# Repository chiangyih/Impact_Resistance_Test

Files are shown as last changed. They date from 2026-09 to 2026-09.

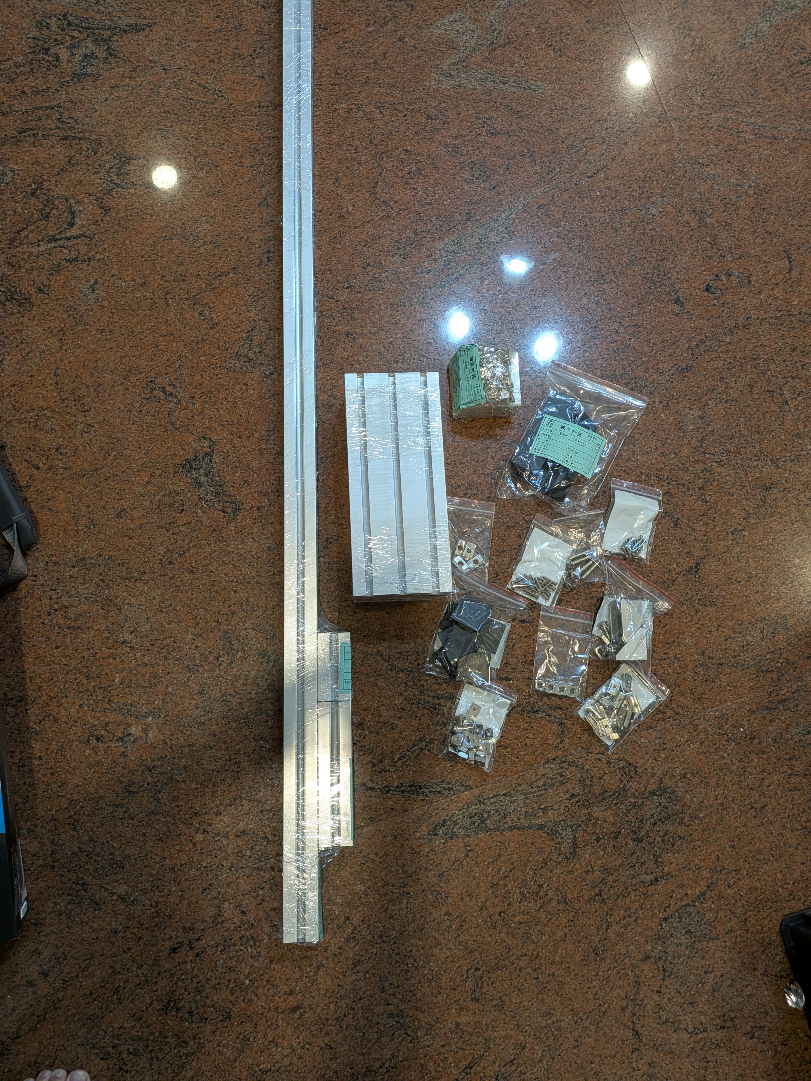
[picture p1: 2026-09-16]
圖片/PXL_20260615_125800659.MP.jpg

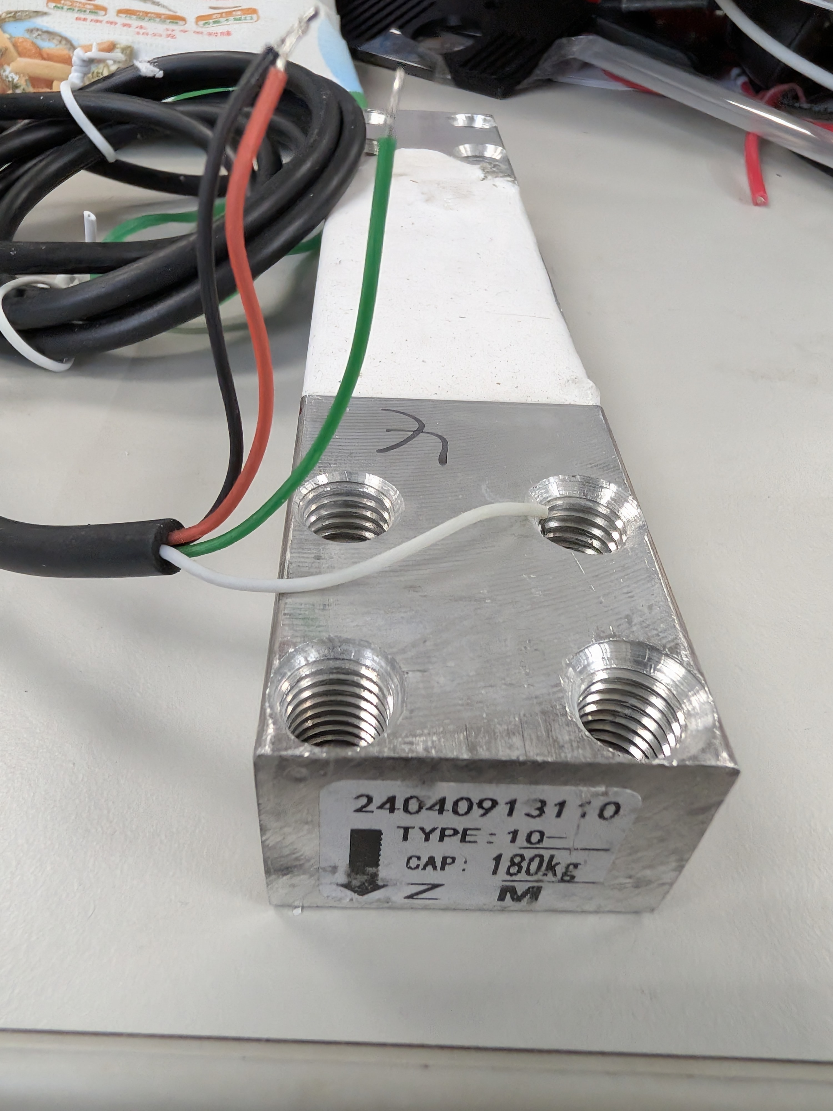
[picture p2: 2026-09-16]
圖片/PXL_20260612_010520091.jpg

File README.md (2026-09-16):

# Impact_Resistance_Test

STF、三浦摺疊與 EVA 落體衝擊緩衝材料試驗平台。

本專案以 NodeMCU-32S（ESP32-WROOM-32）作為控制與資料擷取核心，使用 Adafruit ADXL375 量測掉落平台加速度，使用 Adafruit HX711 搭配荷重元量測底部相對受力，並以兩組 OS25B10 四腳槽型光電開關量測撞擊前近似速度。

## 專案目的

建立可重複的垂直落下衝擊量測系統，比較不同緩衝結構對下列指標的影響：

- 掉落物撞擊前近似速度
- ADXL375 峰值加速度與撞擊作用時間
- Load Cell 傳遞至底座的相對受力
- 緩衝材料的壓縮與永久變形

預計比較的組別包括無緩衝、EVA、PP 三浦摺疊、STF，以及 STF＋三浦摺疊＋EVA 複合結構。

## 實際元件與目前狀態

| 元件 | 目前狀態與用途 |
|---|---|
| NodeMCU-32S／ESP32-WROOM-32 | 主控制器、時間戳與 USB Serial 資料傳輸 |
| Adafruit ADXL375 | ±200 g 三軸加速度計，使用 I²C；照片中的紫色開發板與此型號相符 |
| Adafruit HX711 24-bit ADC | 讀取荷重元；使用 A 通道，RATE 開關規劃使用 80 SPS |
| 四線式 Load Cell | 照片銘牌可讀到 `CAP: 180 kg`；正式校正前仍須以銘牌／資料表確認額定容量與線色 |
| OS25B10 × 2 | 四腳槽型光電開關／光遮斷器，內含紅外線 LED 與光電晶體管；需外接 LED 限流電阻與 Collector 上拉電阻 |
| Relay＋12 V 電磁鐵 | 釋放掉落平台；Relay 型號與觸發邏輯尚待依實物標示確認 |
| 釋放按鈕 | GPIO27，使用內建上拉，按下為 LOW |
| microSD | 尚未由目前照片確認，列為後續選配資料儲存裝置 |

## NodeMCU-32S 腳位總表

這是目前採用的單一腳位配置。未來程式、接線圖與測試紀錄都應以此表為準。

| NodeMCU-32S | 對應元件端子 | 方向 | 用途／備註 |
|---|---|---|---|
| 3V3 | ADXL375 VIN、HX711 VIN、OS25B10 電路 | 電源輸出 | 感測器邏輯電源；不可接 12 V |
| GND | ADXL375 GND、HX711 GND、OS25B10 Emitter／LED Cathode、按鈕、Relay GND | 電源回路 | 邏輯側共地，建議星狀接地 |
| GPIO21 | ADXL375 SDA | I/O | I²C SDA |
| GPIO22 | ADXL375 SCL | I/O | I²C SCL |
| GPIO16 | ADXL375 INT | 輸入（選配） | Data Ready／FIFO／事件中斷；基本輪詢可不接 |
| GPIO17 | ADXL375 I2 | 輸入（選配） | 第二組中斷；目前可不接 |
| GPIO32 | HX711 DATA | 輸入 | HX711 serial data output |
| GPIO33 | HX711 SCK | 輸出 | HX711 serial clock |
| GPIO34 | OS25B10 光閘 1 Collector 節點 | 輸入 | ESP32 輸入專用，沒有內建上拉 |
| GPIO35 | OS25B10 光閘 2 Collector 節點 | 輸入 | ESP32 輸入專用，沒有內建上拉 |
| GPIO26 | Relay IN | 輸出 | 電磁鐵釋放控制；程式需設定高／低觸發 |
| GPIO27 | 釋放按鈕另一端 | 輸入 | 按鈕另一端接 GND，使用 `INPUT_PULLUP` |
| GPIO18 | microSD SCK（選配） | 輸出 | VSPI clock |
| GPIO19 | microSD MISO（選配） | 輸入 | VSPI MISO |
| GPIO23 | microSD MOSI（選配） | 輸出 | VSPI MOSI |
| GPIO5 | microSD CS（選配） | 輸出 | VSPI CS；GPIO5 是啟動相關腳位，SD 模組 CS 應保持上拉 |

GPIO34、GPIO35 只能作輸入，且沒有軟體內建上拉／下拉；OS25B10 必須各自使用外接 10 kΩ 上拉電阻。ADXL375 與 HX711 都使用 3.3 V 邏輯。NodeMCU-32S 不可把 12 V 電磁鐵電源接到 3V3、5V 或 VIN。

## 電源與接地

- NodeMCU-32S 由 USB 供電；感測器由 NodeMCU-32S 的 3V3 供電。
- ADXL375、HX711、OS25B10、按鈕與 Relay 的邏輯側共用 GND。
- 電磁鐵使用獨立 12 V 電源；不要由 ESP32 腳位或 USB 直接供電。
- Relay 模組的 VCC 需依實物標示接額定電源；目前規劃以 5 V Relay 模組為基準。若為非隔離模組，Relay GND 與 ESP32 GND 共地。
- 12 V 高電流線、Relay 線與 Load Cell／I²C 線分開走線，並以星狀方式回到電源地，降低衝擊雜訊。

## ADXL375（Adafruit，I²C）

照片中的紫色板為 Adafruit ADXL375 高 G 加速度計。板上 I²C 預設位址為 `0x53`；I²C 的 SDA、SCL 已有板載上拉與電平轉換，NodeMCU-32S 使用 3.3 V 即可。

| ADXL375 端子 | NodeMCU-32S | 說明 |
|---|---|---|
| VIN | 3V3 | 供電；依板面標示使用 `VIN`，不是 `3Vo` |
| GND | GND | 共地 |
| SDA | GPIO21 | I²C 資料 |
| SCL | GPIO22 | I²C 時脈 |
| CS | 3V3 | I²C 模式；此板預設已拉高，若保持原板設定可不另接 |
| SDO | GND | 使用 I²C 位址 `0x53`；接 3V3 則為 `0x1D` |
| INT | GPIO16（選配） | Data Ready／FIFO／事件中斷 |
| I2 | GPIO17（選配） | 第二組中斷，目前可不接 |
| 3Vo | 不接 | 板上穩壓器的 3.3 V 輸出，不可當作電源輸入 |

ADXL375 應牢固固定在掉落平台上，盡量靠近重心。程式使用 I²C 輪詢時可不接 INT／I2；若要用 Data Ready 或 FIFO 中斷，再接 GPIO16。正式上電前仍應以 I²C scanner 確認 `0x53`。

## HX711（Adafruit）與 Load Cell

照片中的黑色板為 Adafruit HX711 24-bit ADC，板上端子名稱為 `E-`、`A-`、`A+`、`B+`、`B-`、`E+`，邏輯端子為 `VIN`、`GND`、`DATA`、`SCK`、`RATE`。單一四線式荷重元使用 A 通道，B 通道留空。

### HX711 與 NodeMCU-32S

| HX711 端子 | NodeMCU-32S | 說明 |
|---|---|---|
| VIN | 3V3 | 供電；依實物標示使用 `VIN` |
| GND | GND | 共地 |
| DATA | GPIO32 | 資料輸出 |
| SCK | GPIO33 | 時脈輸入 |
| RATE | 不接 GPIO | 使用板上滑動開關；切到 `H` 為 80 SPS，`L` 為 10 SPS |
| VIO（若板上有引出） | 不接 | 板上數位電源穩壓輸出，不是 NodeMCU 電源輸入 |

### Load Cell 與 HX711 端子

| Load Cell 功能／目前照片線色 | HX711 端子 | 備註 |
|---|---|---|
| 激勵正／紅線（暫定） | E+ | 以實際規格或電阻量測確認 |
| 激勵負／黑線（暫定） | E- | 以實際規格或電阻量測確認 |
| 訊號正／綠線（暫定） | A+ | HX711 A 通道 |
| 訊號負／白線（暫定） | A- | HX711 A 通道 |
| B 通道 | B+、B- | 單一荷重元不接 |

紅／黑／綠／白只可作目前接線起點，正式上電前須依荷重元資料表或電阻量測確認。照片銘牌可讀到 `CAP: 180 kg`，因此校正與機構安全檢查暫以 180 kg 額定容量作為待確認資料，不把它當作已完成規格驗證。

Load Cell 機械上應一端固定、一端受力，上方設置剛性壓板；不可將整支樑完全夾死。HX711 最高 80 SPS，適合組別間相對受力比較，不應宣稱為毫秒級真實瞬時峰值力。

## OS25B10 雙光閘

OS25B10 是四腳槽型光電開關／光遮斷器，不是具有 `VCC/GND/OUT` 的數位模組。專案中的實物參考照片為 [OS25B10-紅外線對射光電開關.png](圖片/OS25B10-紅外線對射光電開關.png)。每顆元件需要一個 LED 限流電阻與一個光電晶體管上拉電阻：

```text
每一顆 OS25B10 各自使用一組電阻；兩組輸出節點不可互相短接：

光閘 1：
3.3 V ── 220 Ω ── IR LED Anode
IR LED Cathode ── GND
3.3 V ── 10 kΩ ──┬── Collector
                 └── 輸出節點 ── GPIO34
Emitter ── GND

光閘 2：
3.3 V ── 220 Ω ── IR LED Anode
IR LED Cathode ── GND
3.3 V ── 10 kΩ ──┬── Collector
                 └── 輸出節點 ── GPIO35
Emitter ── GND
```

- 光閘 1 的 Collector 輸出節點接 GPIO34。
- 光閘 2 的 Collector 輸出節點接 GPIO35。
- GPIO34／GPIO35 沒有內建上拉，10 kΩ 必須外接，而且只能拉到 3.3 V。
- 預期未遮光時光電晶體管導通、輸出 LOW；遮光時輸出 HIGH。實際極性仍須在單獨測試時確認。
- OS25B10 四根腳的實體順序目前尚未完成確認。焊接前先用萬用電表二極體檔找出 IR LED 的正負腳，再確認 Collector／Emitter；不可只依封裝外觀猜測。
- 不可將 LED 直接接到 3.3 V，也不可把任何光閘輸出上拉至 5 V。

程式以 `micros()` 記錄兩個 GPIO 的相同邊緣，計算 `v_gate = d / (t2 - t1)`。這是兩閘間平均速度，應稱為「撞擊前近似速度」，不是精確撞擊瞬間速度。

## Relay、電磁鐵與釋放按鈕

### Relay 與 12 V 電磁鐵

Relay 模組的實際型號與觸發邏輯尚待從實物標示確認；目前預留接法如下：

| Relay 端子 | NodeMCU-32S／電源 | 說明 |
|---|---|---|
| IN | GPIO26 | 程式以 `RELAY_ACTIVE_LOW` 選擇高／低觸發 |
| GND | GND | 非隔離模組需共地 |
| VCC | 5 V／VIN 或模組額定電源 | 以 Relay 實物標示為準，不由 GPIO 供電 |

電磁鐵負載側：

```text
獨立 12 V+ ── Relay COM
Relay NO ── 電磁鐵正極
電磁鐵負極 ── 獨立 12 V−
```

電磁鐵兩端並聯飛輪二極體：陰極（有色環端）接電磁鐵正極，陽極接電磁鐵負極。電磁鐵應固定在上方支架，不裝在移動掉落平台上。

### 釋放按鈕

```text
GPIO27 ── 釋放按鈕 ── GND
```

程式設定 `pinMode(27, INPUT_PULLUP)`，按下時讀值為 LOW，並加入按鍵去彈跳。

## microSD（後續選配）

目前尚未從照片確認 microSD 模組，因此不列入已驗證硬體。若後續加入 3.3 V 邏輯相容的 SPI 模組，預留：

| microSD 端子 | NodeMCU-32S |
|---|---:|
| SCK | GPIO18 |
| MISO | GPIO19 |
| MOSI | GPIO23 |
| CS | GPIO5 |
| VCC | 3V3（依模組規格） |
| GND | GND |

GPIO5 是 ESP32 啟動相關腳位，microSD 的 CS 必須在開機時保持適當的高電位；正式接入前要確認模組沒有把 CS 強制拉低。若模組接受 5 V 供電，仍必須確認其輸出到 ESP32 的邏輯不超過 3.3 V。

## 量測與資料品質限制

- 雙光閘應盡量靠近撞擊面；第二光閘到撞擊面的距離需固定或做修正。
- 雙光閘計算的是兩閘間平均速度，不能直接當作撞擊瞬間速度。
- HX711 的取樣率有限，主要用於不同材料組別的相對比較。
- ADXL375 應固定牢靠，避免感測器本體晃動造成假峰值。
- Load Cell 線與 I²C 線遠離 USB、Relay 與電磁鐵高電流線路。
- 目前尚未完成整體實體接線、感測器讀值、Load Cell 校正或正式落下測試。

## Arduino CLI 編譯與燒錄

本專案使用下列 Arduino CLI 執行檔：

```text
C:\Program Files\Arduino CLI\arduino-cli.exe
```

PowerShell 範例：

```powershell
$cli = 'C:\Program Files\Arduino CLI\arduino-cli.exe'
& $cli board list
& $cli compile --fqbn esp32:esp32:nodemcu-32s <sketch-folder>
& $cli upload --port COMx --fqbn esp32:esp32:nodemcu-32s <sketch-folder>
```

正式編譯前先以 `board list` 確認實際 COM 埠，並確認已安裝 ESP32 Arduino core 與 `nodemcu-32s` FQBN。

### 01-irt.ino 第一版簡易測試程式

程式位置為 `01-irt/01-irt.ino`，用途是先確認 ESP32 能否收到下列元件資料：

- Adafruit ADXL375：I²C 掃描、初始化與 X／Y／Z 加速度（m/s²）。
- Adafruit HX711：A 通道增益 128 的原始 ADC 值；未校正、未換算重量。
- OS25B10 光閘一／二：GPIO34／GPIO35 的 HIGH／LOW 狀態。

本測試程式需要安裝 `Adafruit ADXL375`、`Adafruit HX711` 及其相依函式庫；Arduino CLI 可使用下列指令編譯：

```powershell
$cli = 'C:\Program Files\Arduino CLI\arduino-cli.exe'
& $cli lib install 'Adafruit ADXL375' 'Adafruit HX711'
& $cli compile --fqbn esp32:esp32:nodemcu-32s .\01-irt
& $cli upload --port COMx --fqbn esp32:esp32:nodemcu-32s .\01-irt
& $cli monitor --port COMx --config baudrate=115200
```

燒錄前先以 `board list` 確認 `COMx`；序列埠監控視窗應設定為 115200 baud。若 HX711 未就緒，程式等待 1 秒後輸出逾時並繼續顯示其他感測器；OS25B10 必須依接線規格使用外接 10 kΩ 上拉，不能只靠程式設定內建上拉。

## 目前檔案

- `01-irt/01-irt.ino`：第一版簡易感測器接線測試程式，所有程式碼行均附正體中文註解。
- `handoff.md`：完整專題交接紀錄、設計背景與接線修訂。
- `auto-git-watch.ps1`：檔案變更自動 commit／push 監看器。
- `圖片/`：目前取得的元件與機構照片。
- `零件1.stp`：STEP 機械模型。
- `零件1.stl`：STL 網格模型。

## Git 自動同步

遠端儲存庫：<https://github.com/chiangyih/Impact_Resistance_Test>

目前已設定目前 Windows 使用者登入時啟動自動監看器。監看器每 5 秒檢查變更，等待 3 秒後自動建立 commit 並推送至 `origin/main`；不使用 force push。紀錄位於：

```text
%LOCALAPPDATA%\Impact_Resistance_Test\auto-git-watch.log
```

所有新增或修改的檔案都可能被自動提交，請勿將密碼、Token、私鑰或其他秘密放入此專案資料夾。

## 後續工作

1. 用萬用電表確認兩顆 OS25B10 的 LED／Collector／Emitter 實體腳位。
2. 完成雙光閘輸出波形與必要的比較器／施密特觸發器評估。
3. 以 I²C scanner 與 Adafruit Arduino library 完成 ADXL375 單獨讀值測試。
4. 依 Load Cell 規格確認線色、額定容量，完成 HX711 靜態校正。
5. 確認 Relay 模組額定電壓與 HIGH／LOW trigger，完成電磁鐵空載釋放測試。
6. 完成 ESP32 時間同步、雙光閘中斷與資料記錄程式。
7. 先進行低高度、低重量測試，再進入緩衝材料比較實驗。

## 參考資料

- [Adafruit HX711 24-bit ADC](https://learn.adafruit.com/adafruit-hx711-24-bit-adc)
- [Adafruit HX711 Pinouts](https://learn.adafruit.com/adafruit-hx711-24-bit-adc/pinouts)
- [Adafruit ADXL375 Pinouts](https://learn.adafruit.com/adafruit-adxl375/pinouts)
- [Seeed Studio OS25B10 Photo Interrupter](https://wiki.seeedstudio.com/ja/Photo_interrupter_OS25B10/)
- [Espressif Arduino-ESP32 NodeMCU-32S variant](https://github.com/espressif/arduino-esp32/blob/master/variants/nodemcu-32s/pins_arduino.h)
- [Espressif ESP32-WROOM-32 datasheet](https://documentation.espressif.com/esp32-wroom-32_datasheet_en.html)

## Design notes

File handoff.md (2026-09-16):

# handoff.md

## 專題交接紀錄：STF＋三浦摺疊衝擊緩衝試驗台

### 一、專題核心目標
本專題主要希望建立一套可重複的落下衝擊試驗裝置，用來比較不同緩衝結構對衝擊的吸收與減緩效果。

目前關注的緩衝結構包含：
- STF（Shear Thickening Fluid，剪切增稠流體）
- 三浦摺疊（Miura-ori）結構
- EVA 內襯
- 上述材料的複合組合

研究核心問題：
> STF、三浦摺疊與 EVA 是否能透過延長撞擊作用時間、增加變形行程與耗散能量，降低峰值加速度與傳遞到底部的衝擊力？

---

## 二、目前使用／規劃的主要硬體

### 1. ESP32
用途：
- 作為整套裝置的控制與資料擷取核心
- 控制電磁鐵釋放
- 讀取 ADXL375
- 讀取 HX711
- 讀取雙光閘
- 記錄釋放與通過光閘的時間
- 計算速度、合成加速度等資料
- 可搭配 microSD 儲存 CSV
- 可透過 USB Serial 傳輸資料到電腦

NodeMCU-32S 的目前接線配置如下；完整端子對照與注意事項見本文件末尾「實際元件接線修訂」及 `README.md`：
- ADXL375 `VIN` → 3V3；`SDA` → GPIO21；`SCL` → GPIO22
- ADXL375 `INT` → GPIO16（選配）；`I2` → GPIO17（選配）
- ADXL375 `CS` → 3V3（I²C）；`SDO` → GND（I²C 位址 `0x53`）
- HX711 `VIN` → 3V3；`DATA` → GPIO32；`SCK` → GPIO33
- HX711 `RATE` 不占用 GPIO，使用板上開關；`H` 為 80 SPS、`L` 為 10 SPS
- OS25B10 光閘 1 Collector 節點 → GPIO34；光閘 2 Collector 節點 → GPIO35
- Relay `IN` → GPIO26
- 釋放按鈕 → GPIO27，按鈕另一端接 GND，使用 `INPUT_PULLUP`
- microSD（後續選配）：SCK → GPIO18、MISO → GPIO19、MOSI → GPIO23、CS → GPIO5

所有感測器邏輯使用 3.3 V 並與 ESP32 共地。GPIO34／GPIO35 為輸入專用腳位，沒有內建上拉／下拉，OS25B10 必須外接 10 kΩ 上拉電阻。

### 2. ADXL375
用途：
- 高 g 值三軸加速度感測器
- 量測掉落滑塊撞擊瞬間的加速度

本專案實際使用照片中的 Adafruit ADXL375 ±200 g breakout。使用 I²C 時，`VIN` 接 NodeMCU-32S 的 3V3，`SDA` 接 GPIO21，`SCL` 接 GPIO22；`CS` 維持高電位以啟用 I²C，`SDO` 接 GND 使用預設位址 `0x53`。`3Vo` 是板上穩壓器輸出，不可當作電源輸入。此板 SDA／SCL 已有板載 10 kΩ 上拉，通常不需再並接 4.7 kΩ。

可取得：
- X 軸加速度 ax
- Y 軸加速度 ay
- Z 軸加速度 az
- 合成加速度
- 峰值加速度
- 撞擊作用時間
- 反彈震盪情形

合成加速度：
a_total = sqrt(ax^2 + ay^2 + az^2)

安裝：
- 固定在掉落滑塊上
- 建議靠近滑塊重心
- 必須固定牢靠，避免感測器本體晃動造成假峰值

### 3. Load Cell
用途：
- 安裝於底部衝擊平台
- 量測撞擊後傳遞至底部平台的受力

目前實物：
- 照片中的荷重元銘牌可讀到 `CAP: 180 kg`；額定容量仍須以完整銘牌／資料表確認
- 不再沿用前版「50 kg」的暫定假設
- 正式測試前需完成荷重元線色確認、機械安裝檢查與 HX711 校正

可量測：
- 荷重元受力原始訊號
- 經校正後的力
- 相對峰值衝擊力
- 不同緩衝組別間的受力差異

注意：
- Load Cell 不能整支完全夾死
- 一般應一端固定、一端受力，使樑體能正常微小變形

### 4. HX711
用途：
- HX711 不是感測器，而是 Load Cell 的放大器與 ADC
- 將 Load Cell 微小電壓訊號放大並轉成 ESP32 可讀取的數位值

訊號鏈：
Load Cell → HX711 → ESP32

目前接線起點（線色仍須量測確認）：
- Load Cell 紅線 → HX711 `E+`
- 黑線 → `E-`
- 綠線 → `A+`
- 白線 → `A-`
- 單一荷重元不使用 `B+`／`B-`

HX711 接 ESP32：
- `VIN` → 3.3V
- `GND` → GND
- `DATA` → GPIO32
- `SCK` → GPIO33
- `RATE` 不接 GPIO，使用板上滑動開關；`H` 為 80 SPS、`L` 為 10 SPS
- `VIO`（若有引出）為板上輸出，保持不接

重要限制：
- HX711 取樣率有限
- 適合科展級相對衝擊力比較
- 不適合宣稱為毫秒級真實瞬時峰值力的精密量測

建議報告敘述：
> 本研究使用 Load Cell 搭配 HX711 量測衝擊傳遞至底座之相對受力變化。由於 HX711 取樣率有限，所得峰值主要用於組別間相對比較，而非精密瞬時峰值力。

---

## 三、線性滑軌與雙滑塊

### 1. 線性滑軌
目前規劃：
- MGN12
- 長度 1000 mm
- 垂直安裝

作用：
- 限制掉落平台只能沿垂直方向移動
- 避免旋轉、偏移與斜撞
- 提高撞擊位置與姿態的一致性
- 提升實驗可重複性

原理：
- 滑塊內部使用循環鋼珠
- 以滾動摩擦降低阻力
- 鋼珠沿精密溝槽滾動，使滑塊做低摩擦直線運動

注意：
- 線性滑軌仍有摩擦
- 實際掉落加速度通常小於 g
- 因此不能只靠 v = sqrt(2gh) 推估真實撞擊速度
- 需要雙光閘校正

### 2. 兩個滑塊
目前建議：
- 同一支線性滑軌上使用兩個滑塊
- 兩個滑塊用同一片剛性掉落平台連接
- 一起上下移動
- 建議間距約 8～12 cm

上滑塊：
- 穩定掉落平台上半部
- 抵抗電磁鐵吸附與配重偏心造成的旋轉
- 改善釋放瞬間姿態

下滑塊：
- 穩定撞擊頭位置
- 降低下半部擺動
- 確保撞擊頭垂直撞在測試材料中心

共同作用：
- 增加抗旋轉能力
- 降低偏心造成的卡滯
- 提高下落與撞擊一致性

---

## 四、雙光閘

### 1. 作用
雙光閘不是用來量加速度或衝擊力。

主要用途：
> 量測掉落滑塊在撞擊前的實際速度。

原因：
- 線性滑軌有摩擦
- 實際撞擊速度不一定等於理論自由落下速度

### 2. 原理
在軌道下段設置兩個光電遮斷感測器：

掉落方向
↓
光閘1
↓ 固定距離 d
光閘2
↓
撞擊面

ESP32 記錄：
- 光閘1時間 t1
- 光閘2時間 t2

兩閘間平均速度：
v = d / (t2 - t1)

### 3. 重要修正
已確認：
> 滑塊通過第二個光閘後，只要尚未撞擊，速度仍會繼續增加。

因此雙光閘直接計算的是：
> 光閘1到光閘2之間的平均速度

而不是精確撞擊瞬間速度。

建議：
- 光閘1、2間距約 5 cm
- 光閘2盡量靠近撞擊面
- 光閘2到撞擊面建議約 1～2 cm
- 將此速度稱為「撞擊前近似速度」

更精確方案：
1. 利用遮光片寬度與通過光閘2的遮光時間估算局部速度
2. 估算滑軌有效加速度後修正至撞擊面
3. 若需要更高精度，可增加第三個光閘

---

## 五、電磁鐵釋放裝置

### 1. 作用
> 在實驗開始前吸住掉落滑塊，ESP32 控制 Relay 斷電後，讓滑塊從固定高度穩定釋放。

電磁鐵不負責驅動滑塊，也不應承受撞擊力。

### 2. 安裝方式
電磁鐵應：
- 固定在滑軌最上方固定架或橫樑
- 吸附面朝下
- 滑塊上方裝平整鐵片給電磁鐵吸住

結構：
上方固定架
↓
電磁鐵
↓
鐵片
↓
掉落平台
↓
兩個線性滑塊
↓
撞擊頭

重要對準：
- 電磁鐵中心
- 鐵片中心
- 滑塊整體重心
- 撞擊頭中心
- 測試材料中心

應盡量在同一直線上。

### 3. 固定方式
建議：
- L 型角碼
- 小型固定板
- 使用電磁鐵附帶螺絲
- 不建議只用熱熔膠或雙面膠

鐵片：
- 一般鐵片或低碳鋼
- 約 1～2 mm 厚
- 不建議鋁片
- 不鏽鋼可能吸力不足

若斷電後殘磁造成不易釋放，可貼極薄透明膠帶減少殘磁黏附。

### 4. Relay 控制
目前規劃不用 MOSFET，採 Relay 控制。

電磁鐵：
- 使用獨立 12V 電源
- 不可直接由 ESP32 供電

接線：
12V+ → Relay COM
Relay NO → 電磁鐵+
電磁鐵- → 12V-

ESP32：
GPIO26 → Relay IN
GND → Relay GND
5V / VIN → Relay VCC

電磁鐵兩端須加飛輪二極體：
- 陰極（白線端）→ 電磁鐵正極
- 陽極 → 電磁鐵負極

可用：
- 1N4007
- 1N5819
- SS14
- FR107

---

## 六、電磁鐵控制程式邏輯

建議：
開機
↓
Relay 啟動
↓
電磁鐵通電吸住滑塊
↓
等待按鈕
↓
ESP32 啟動資料記錄
↓
Relay 斷電
↓
電磁鐵釋放
↓
記錄釋放時間 t0

目前程式建議：
- Relay IN → GPIO26
- 釋放按鈕 → GPIO27
- 使用 INPUT_PULLUP
- 按下為 LOW
- 正式實驗時間基準建議用 micros()
- Serial 可設：
  - a → ARM
  - r → RELEASE

注意：
- Relay 可能為 LOW trigger 或 HIGH trigger
- 程式需設定 RELAY_ACTIVE_LOW

---

## 七、衝擊過程與物理原理

### 1. 落下前
重力位能：
E_p = mgh

### 2. 撞擊前
實際撞擊動能估計：
E_k = 1/2 mv^2

### 3. 撞擊瞬間
衝量：
J = ∫Fdt = Δp

簡化：
F_avg ≈ Δp / Δt

因此：
- 停止時間越短 → 力越大
- 停止時間越長 → 平均力越小

### 4. 壓縮距離
E = ∫Fdx

簡化：
F_avg ≈ E / s

因此：
- 停止距離越短 → 平均力越大
- 停止距離越長 → 平均力越小

---

## 八、不同緩衝材料的作用

### STF
- 高速受剪切時增稠
- 增加顆粒摩擦與流動阻力
- 形成 hydrocluster / force chain / jamming
- 以黏滯、摩擦與流變耗散撞擊能量

注意：
- 太薄、太濃、封裝太滿都可能使峰值反而升高
- STF 較適合作為高速阻尼層，而非唯一緩衝層

### 三浦摺疊
- 透過幾何變形、摺線轉動、面板彎曲吸能
- 增加壓縮行程
- 延長停止距離與時間
- 有機會降低峰值衝擊力

### EVA
- 泡棉壓縮吸能
- 分散接觸壓力
- 防止硬接觸
- 降低觸底造成的第二峰值
- 降低反彈與局部壓力集中

核心觀念：
> 好的緩衝不是讓力消失，而是把原本「短時間、高峰值」的衝擊，轉換成「較長時間、較低峰值」的受力過程。

---

## 九、主要量測值

直接量測：
1. 掉落物質量 m
2. 掉落高度 h
3. 光閘1時間 t1
4. 光閘2時間 t2
5. 光閘間距 d
6. X 軸加速度 ax
7. Y 軸加速度 ay
8. Z 軸加速度 az
9. HX711 原始讀值
10. 測試材料厚度
11. 三浦摺疊測試前後高度
12. 電磁鐵釋放時間 t0

---

## 十、主要計算值

1. 理論位能：E_p = mgh
2. 理論速度：v_theory = sqrt(2gh)
3. 雙光閘平均速度：v_gate = d / (t2 - t1)
4. 實際撞擊動能估計：E_k = 1/2 mv^2
5. 合成加速度：a_total = sqrt(ax^2 + ay^2 + az^2)
6. 峰值加速度 a_max
7. 撞擊作用時間 Δt_impact
8. 校正後受力 F
9. 相對峰值衝擊力 F_max
10. 峰值加速度降低率
11. 相對衝擊力降低率
12. 永久變形量 ΔH = H0 - H1
13. 平均值、標準差、變異係數

---

## 十一、核心分析指標

建議主打：
1. 實際撞擊前速度
2. 實際撞擊動能
3. 峰值加速度
4. 撞擊作用時間
5. 相對峰值衝擊力
6. 加速度降低率
7. 衝擊力降低率
8. 永久變形量

---

## 十二、建議測試組別

至少：
- A：無緩衝
- B：EVA
- C：PP 三浦摺疊
- D：STF
- E：STF + PP 三浦摺疊 + EVA

若時間足夠：
- STF + EVA
- 三浦摺疊 + EVA
- STF + 三浦摺疊

每組建議至少 5 次。

---

## 十三、程式需要負責的五大模組

### 1. 電磁鐵控制
- Relay 控制通電 / 斷電
- 記錄釋放時間 t0

### 2. 雙光閘
- 使用 GPIO 中斷
- 記錄 t1、t2
- 計算通過速度

### 3. ADXL375
- 持續高速讀取
- 記錄 ax、ay、az
- 計算合成加速度
- 找峰值加速度
- 估算撞擊作用時間

### 4. Load Cell + HX711
- 讀取原始值
- 依校正係數換算受力
- 記錄相對峰值力

### 5. 時間同步與資料儲存
所有事件共用同一時間軸：

t = 0        電磁鐵釋放
t = ...      光閘1
t = ...      光閘2
t = ...      撞擊開始
t = ...      加速度峰值
t = ...      Load Cell 相對力峰值
t = ...      撞擊結束

建議：
- 使用 micros()
- microSD 儲存 CSV
- 或 USB Serial 傳至電腦

---

## 十四、建議程式狀態機

WAIT
↓
ARMED
↓
RECORDING
↓
RELEASE
↓
FALLING
↓
IMPACT
↓
FINISHED
↓
READY

意義：
- WAIT：等待操作
- ARMED：電磁鐵吸住滑塊
- RECORDING：感測器預先記錄
- RELEASE：電磁鐵斷電
- FALLING：記錄光閘
- IMPACT：高速記錄衝擊資料
- FINISHED：停止本次試驗
- READY：準備下一次

---

## 十五、microSD 建議

建議 CSV 欄位：

trial_id,group,time_us,release_state,gate1,gate2,ax_g,ay_g,az_g,a_total_g,hx711_raw,force_N

每次實驗摘要：
- trial_id
- group
- mass_g
- height_cm
- v_actual
- impact_energy_J
- peak_acceleration_g
- peak_force_N
- impact_duration_ms
- permanent_deformation_mm

---

## 十六、目前最重要的技術注意事項

1. ADXL375 要牢固固定在掉落滑塊。
2. Load Cell 上方應設剛性上壓板。
3. HX711 適合相對力比較，不宜宣稱精密瞬時峰值。
4. 線性滑軌要垂直並固定牢靠。
5. 兩個滑塊建議間距 8～12 cm。
6. 滑塊重心要靠近滑軌中心線。
7. 電磁鐵固定在上方固定架，不裝在移動滑塊上。
8. 電磁鐵、鐵片、滑塊重心、撞擊頭、測試材料中心盡量對齊。
9. 電磁鐵使用獨立 12V 電源。
10. Relay 控制電磁鐵時必須加飛輪二極體。
11. 雙光閘應盡量靠近撞擊面。
12. 雙光閘測得的是兩閘間平均速度，不是精確撞擊瞬間速度。
13. 若需更精確，可用遮光片寬度計算第二光閘附近局部速度。
14. 正式程式應重視時間同步，建議使用 micros()。
15. 若測試材料厚度不同，應保持光閘2到實際撞擊面的距離一致或做修正。

---

## 十七、目前專題整體架構

ESP32
├─ ADXL375 → 加速度
├─ HX711 → Load Cell → 底部相對受力
├─ 光閘1
├─ 光閘2 → 撞擊前速度
├─ Relay → 12V 電磁鐵 → 滑塊釋放
└─ microSD（建議）→ CSV 資料記錄

機械結構：

上方固定架
↓
電磁鐵
↓
鐵片
↓
掉落平台
├─ 配重
├─ ADXL375
├─ 上滑塊
├─ 下滑塊
└─ 撞擊頭
↓
雙光閘
↓
STF / 三浦摺疊 / EVA
↓
上壓板
↓
Load Cell
↓
底座

---

## 十八、後續建議優先工作

1. 確認 MGN12 滑軌與兩滑塊實際機械尺寸
2. 設計掉落平台與撞擊頭
3. 完成電磁鐵固定架
4. 完成鐵片與電磁鐵對準
5. 完成 Relay 控制與空載釋放測試
6. 完成雙光閘安裝
7. 完成 ADXL375 單獨讀值測試
8. 完成 Load Cell + HX711 靜態校正
9. 完成整體 ESP32 同步程式
10. 先進行低高度、低重量落下測試
11. 確認感測器不飽和、資料不遺失
12. 再進入正式 STF / 三浦摺疊材料比較實驗

---

## 十九、一句話總結

> 本專題利用線性滑軌與電磁鐵建立可重複落下機構，透過雙光閘量測撞擊前速度、ADXL375 量測撞擊加速度、Load Cell + HX711 量測底部傳遞受力，進而比較 STF、三浦摺疊與 EVA 等緩衝結構對峰值加速度、衝擊力、撞擊作用時間與結構變形的影響。

---

## 二十、2026-09-14 本次工作進度

### 1. Git 版本控管與自動同步

已完成：

- 專案資料夾已建立 Git 儲存庫，主要分支為 `main`。
- 已設定遠端：`https://github.com/chiangyih/Impact_Resistance_Test.git`。
- 遠端原有的 `README.md` 已保留，並以一般合併方式整合，未使用強制推送。
- 已建立 `auto-git-watch.ps1`，功能如下：
  - 每 5 秒檢查專案檔案變更。
  - 變更穩定 3 秒後執行 `git add --all`。
  - 自動建立帶有時間的 commit。
  - 自動執行 `git push`。
  - 不執行 force push；push 失敗時保留本地 commit 並記錄錯誤。
- Windows 工作排程建立受到目前權限限制，因此改用目前使用者的登入啟動項：
  `Impact_Resistance_Test_AutoGit`。
- 監看紀錄位置：
  `%LOCALAPPDATA%\Impact_Resistance_Test\auto-git-watch.log`
- 已完成端到端驗證：自動產生 commit `c0c4dee` 並成功推送；目前本地 `main` 與 `origin/main` 同步。
- Git 認證沿用 Windows Git Credential Manager，未將密碼、Token 或私鑰寫入專案檔案。

目前專案檔案：

- `README.md`
- `handoff.md`
- `auto-git-watch.ps1`
- `圖片/`（元件與機構照片）
- `零件1.stp`
- `零件1.stl`

### 2. ESP32 感測電路第一版規劃（已依實物修訂）

目前以 NodeMCU-32S、3.3 V 邏輯為基準：

| 功能 | ESP32 腳位 | 接線規劃 |
|---|---:|---|
| ADXL375 SDA | GPIO21 | I²C SDA |
| ADXL375 SCL | GPIO22 | I²C SCL |
| HX711 DATA | GPIO32 | 資料輸出 |
| HX711 SCK | GPIO33 | 時脈輸入 |
| 雙光閘 1 | GPIO34 | 光電晶體管輸出 |
| 雙光閘 2 | GPIO35 | 光電晶體管輸出 |
| ADXL375 INT（選配） | GPIO16 | Data Ready／FIFO／事件中斷 |
| ADXL375 I2（選配） | GPIO17 | 第二組中斷 |
| Relay IN | GPIO26 | 電磁鐵釋放控制 |
| 釋放按鈕 | GPIO27 | 按鈕另一端接 GND，使用 INPUT_PULLUP |
| microSD SCK（選配） | GPIO18 | VSPI |
| microSD MISO（選配） | GPIO19 | VSPI |
| microSD MOSI（選配） | GPIO23 | VSPI |
| microSD CS（選配） | GPIO5 | VSPI；GPIO5 為啟動相關腳位 |

ADXL375：

- 本專案實際使用 Adafruit ADXL375 ±200 g breakout，I²C 預設位址為 `0x53`。
- 開發板 `VIN` → NodeMCU-32S 3.3 V，`GND` 共地；`3Vo` 是板上輸出，保持不接。
- `SDA` → GPIO21，`SCL` → GPIO22。
- `CS` 拉至 3.3 V 以使用 I²C；`SDO` 接 GND 使用 `0x53`，接 3.3 V 則使用 `0x1D`。
- 此 Adafruit breakout 的 SDA／SCL 已有板載 10 kΩ 上拉與電平轉換，通常不需再加 4.7 kΩ。
- `INT` 可接 GPIO16，`I2` 可接 GPIO17；只使用 I²C 輪詢時可不接。
- 若後續需要較高資料率，再評估改用 SPI。

HX711 與 Load Cell：

- 本專案實際使用 Adafruit HX711 breakout；`VIN` 使用 3.3 V，`DATA` 接 GPIO32，`SCK` 接 GPIO33，GND 共地。
- `RATE` 不占用 ESP32 GPIO，使用板上滑動開關；`H` 為 80 SPS、`L` 為 10 SPS。
- `VIO`（若有引出）是板上數位電源輸出，保持不接。
- Load Cell 的激勵線接 `E+`／`E-`，訊號線接 `A+`／`A-`。
- 照片中的四線荷重元銘牌可讀到 `CAP: 180 kg`；紅／黑／綠／白線色僅作接線起點，實際仍須依荷重元資料表或電阻量測確認。
- 單一荷重元不使用 `B+`／`B-`。
- HX711 適合相對受力與低速荷重比較，不將其結果宣稱為毫秒級真實瞬時峰值力。

### 3. OS25B10 雙光閘修正

已確認目前選用的 `OS25B10` 是四腳槽型光電開關／光遮斷器，不是具備 `VCC/GND/OUT` 的數位模組；實物參考照片為 `圖片/OS25B10-紅外線對射光電開關.png`。每個光閘建議使用：

```text
光閘 1（獨立一組電阻）：
3.3 V ── 220 Ω ── IR LED Anode
IR LED Cathode ── GND
3.3 V ── 10 kΩ ──┬── Collector
                 └── 輸出節點 ── GPIO34
Emitter ── GND

光閘 2（獨立一組電阻）：
3.3 V ── 220 Ω ── IR LED Anode
IR LED Cathode ── GND
3.3 V ── 10 kΩ ──┬── Collector
                 └── 輸出節點 ── GPIO35
Emitter ── GND
```

- 光閘 1 輸出接 GPIO34，光閘 2 輸出接 GPIO35。
- GPIO34／GPIO35 為輸入專用腳位，沒有內建上拉電阻，因此必須使用外接 10 kΩ。
- 未遮光時光電晶體管導通，輸出通常為 LOW；遮光時輸出被拉高為 HIGH。
- 四根腳位的實際順序尚未完成確認；正式焊接前須用二極體檔找出 LED 腳位，再確認 Collector／Emitter。
- 不可將 OS25B10 的任何輸出上拉至 5 V，也不可把 LED 直接接到 3.3 V。

### 4. 已驗證與待完成事項

已驗證：

1. Git 儲存庫、遠端 `origin` 與 `main` 分支正常。
2. 自動檔案監看、commit 與 push 已實際成功執行。
3. 目前尚未對 ESP32、ADXL375、HX711、Load Cell 或 OS25B10 進行完整實體接線與量測；元件型號與照片辨識已完成初步確認。

待完成：

1. 確認 OS25B10 實際腳位順序與遮光輸出波形。
2. 完成雙光閘原理圖與必要的比較器／施密特觸發器評估。
3. 以 I²C scanner 確認 ADXL375 位址並完成單獨讀值測試。
4. 依荷重元規格確認線色與額定容量，完成 Load Cell＋HX711 靜態校正。
5. 確認 Relay 模組額定電壓與 HIGH／LOW trigger，完成電磁鐵空載釋放測試。
6. 完成 ESP32 時間同步、雙光閘中斷與資料記錄程式。
7. 使用 Arduino CLI 進行 NodeMCU-32S 編譯與燒錄測試。
8. 先進行低高度、低重量測試，再進行正式緩衝材料比較。

---

## 二十一、2026-09-16 實際元件接線對應修訂

本節為目前最具體的接線版本，並覆蓋前文僅以「建議」描述的腳位。`README.md` 也已同步更新。

### 1. 已由照片確認的元件

- NodeMCU-32S／ESP32-WROOM-32：主控制器。
- Adafruit ADXL375 紫色 breakout：±200 g 三軸加速度計，使用 I²C。
- Adafruit HX711 黑色 breakout：24-bit ADC，使用 A 通道讀取荷重元。
- 四線式 Load Cell：照片銘牌可讀到 `CAP: 180 kg`；完整額定規格與線色仍須再確認。
- 圖片資料夾內另可見線性滑軌、鋁合金基座與安裝零件。

OS25B10 的實物照片已補充為 `圖片/OS25B10-紅外線對射光電開關.png`，可確認其為四腳槽型光電開關／光遮斷器，內含紅外線 LED 與光電晶體管；但四腳實體順序仍需依實物量測確認。Relay、釋放按鈕與 microSD 的功能已納入系統規劃，其中 Relay 型號／觸發邏輯及 microSD 模組目前仍需依實物確認。

### 2. NodeMCU-32S 腳位總表

| NodeMCU-32S | 實際／規劃元件端子 | 方向 | 說明 |
|---|---|---|---|
| 3V3 | ADXL375 VIN、HX711 VIN、OS25B10 電路 | 電源 | 感測器使用 3.3 V；不可接 12 V |
| GND | ADXL375 GND、HX711 GND、OS25B10、按鈕、Relay 邏輯側 | 電源 | 邏輯側共地，建議星狀接地 |
| GPIO21 | ADXL375 SDA | I/O | I²C SDA |
| GPIO22 | ADXL375 SCL | I/O | I²C SCL |
| GPIO16 | ADXL375 INT（選配） | 輸入 | Data Ready／FIFO／事件中斷 |
| GPIO17 | ADXL375 I2（選配） | 輸入 | 第二組中斷 |
| GPIO32 | HX711 DATA | 輸入 | HX711 資料輸出 |
| GPIO33 | HX711 SCK | 輸出 | HX711 時脈 |
| GPIO34 | OS25B10 光閘 1 Collector 節點 | 輸入 | 輸入專用，沒有內建上拉 |
| GPIO35 | OS25B10 光閘 2 Collector 節點 | 輸入 | 輸入專用，沒有內建上拉 |
| GPIO26 | Relay IN | 輸出 | 電磁鐵釋放；需設定高／低觸發 |
| GPIO27 | 釋放按鈕 | 輸入 | 按鈕另一端接 GND，使用 `INPUT_PULLUP` |
| GPIO18 | microSD SCK（選配） | 輸出 | VSPI clock |
| GPIO19 | microSD MISO（選配） | 輸入 | VSPI MISO |
| GPIO23 | microSD MOSI（選配） | 輸出 | VSPI MOSI |
| GPIO5 | microSD CS（選配） | 輸出 | VSPI CS；開機時需保持適當高電位 |

### 3. Adafruit ADXL375 實際接法

| ADXL375 端子 | NodeMCU-32S | 備註 |
|---|---|---|
| `VIN` | 3V3 | 供電；`3Vo` 是板上輸出，不可拿來供電 |
| `GND` | GND | 共地 |
| `SDA` | GPIO21 | I²C 資料 |
| `SCL` | GPIO22 | I²C 時脈 |
| `CS` | 3V3 | I²C 模式；板上預設已拉高，可保持原設定 |
| `SDO` | GND | I²C 位址 `0x53`；接 3V3 則為 `0x1D` |
| `INT` | GPIO16（選配） | 可不接，輪詢模式不需要 |
| `I2` | GPIO17（選配） | 第二組中斷，可不接 |
| `3Vo` | 不接 | 穩壓器 3.3 V 輸出 |

Adafruit breakout 的 SDA／SCL 已有板載 10 kΩ 上拉與電平轉換，通常不需再並接外部 4.7 kΩ。正式上電後先以 I²C scanner 確認 `0x53`。

### 4. Adafruit HX711 與荷重元實際接法

HX711：

- `VIN` → NodeMCU-32S `3V3`
- `GND` → `GND`
- `DATA` → GPIO32
- `SCK` → GPIO33
- `RATE` 不接 GPIO，使用板上滑動開關；`H` 為 80 SPS，`L` 為 10 SPS
- `VIO`（若有引出）為板上輸出，保持不接

單一四線式荷重元使用 A 通道：

| 荷重元功能／照片線色（暫定） | HX711 端子 |
|---|---|
| 激勵正／紅線 | `E+` |
| 激勵負／黑線 | `E-` |
| 訊號正／綠線 | `A+` |
| 訊號負／白線 | `A-` |
| 未使用的第二通道 | `B+`、`B-` 保持不接 |

上述紅／黑／綠／白僅為照片與常見配置的接線起點；正式上電前仍要用資料表或電阻量測確認。照片可讀到 `CAP: 180 kg`，在規格確認完成前不得把此容量視為已驗證值。HX711 最高 80 SPS，量測結果僅作相對受力比較。

### 5. OS25B10 雙光閘電路

OS25B10 是四腳槽型光電開關／光遮斷器，每顆各使用一組 220 Ω LED 限流電阻與 10 kΩ 光電晶體管上拉電阻；實物照片為 `圖片/OS25B10-紅外線對射光電開關.png`：

```text
光閘 1（獨立一組電阻）：
3.3 V ── 220 Ω ── IR LED Anode
IR LED Cathode ── GND
3.3 V ── 10 kΩ ──┬── Collector
                 └── 輸出節點 ── GPIO34
Emitter ── GND

光閘 2（獨立一組電阻）：
3.3 V ── 220 Ω ── IR LED Anode
IR LED Cathode ── GND
3.3 V ── 10 kΩ ──┬── Collector
                 └── 輸出節點 ── GPIO35
Emitter ── GND
```

上圖的兩個 Collector 節點是分開的兩組電路，不是互相短接。GPIO34／GPIO35 沒有內建上拉，且輸出節點只能拉到 3.3 V。預期未遮光為 LOW、遮光為 HIGH，但實際極性需單獨量測確認。四腳實體順序尚未確認，焊接前先用萬用電表二極體檔找出 LED 腳位，再確認 Collector／Emitter。

### 6. Relay、電磁鐵與按鈕

Relay 邏輯側目前預留：

- `IN` → GPIO26
- `GND` → ESP32 GND（非隔離模組）
- `VCC` → Relay 實物標示的額定電源；目前以 5 V 模組為基準

電磁鐵負載側使用獨立 12 V：

```text
12 V+ ── Relay COM
Relay NO ── 電磁鐵正極
電磁鐵負極 ── 12 V−
```

電磁鐵兩端並聯飛輪二極體，陰極（有色環端）接正極，陽極接負極。Relay 型號與 HIGH／LOW trigger 尚未確認，程式需保留 `RELAY_ACTIVE_LOW` 設定。

釋放按鈕接法：

```text
GPIO27 ── 按鈕 ── GND
```

程式使用 `INPUT_PULLUP`，按下為 LOW，並加入去彈跳。

### 7. microSD 選配接法

目前未由照片確認 microSD 模組。若後續使用 3.3 V 邏輯相容的 SPI 模組，接 `SCK/GPIO18`、`MISO/GPIO19`、`MOSI/GPIO23`、`CS/GPIO5`、`VCC/3V3`、`GND/GND`；GPIO5 為啟動相關腳位，需確認 CS 開機時不被強制拉低。

### 8. Arduino CLI 工具

ESP32 程式使用：

```text
C:\Program Files\Arduino CLI\arduino-cli.exe
```

編譯與燒錄前先用 `board list` 確認 COM 埠，並確認 ESP32 Arduino core 與 `esp32:esp32:nodemcu-32s` FQBN 已安裝。所有實體接線與感測器讀值仍須先完成低風險測試，再進行正式落下試驗。

### 9. 官方參考

- Adafruit HX711：<https://learn.adafruit.com/adafruit-hx711-24-bit-adc>
- Adafruit HX711 Pinouts：<https://learn.adafruit.com/adafruit-hx711-24-bit-adc/pinouts>
- Adafruit ADXL375 Pinouts：<https://learn.adafruit.com/adafruit-adxl375/pinouts>
- Seeed Studio OS25B10 Photo Interrupter：<https://wiki.seeedstudio.com/ja/Photo_interrupter_OS25B10/>
- Arduino-ESP32 NodeMCU-32S 腳位定義：<https://github.com/espressif/arduino-esp32/blob/master/variants/nodemcu-32s/pins_arduino.h>

### 10. 2026-09-16 第一版簡易測試程式

已新增 `01-irt/01-irt.ino`，這是目前第一版的簡易測試程式，目的只在確認 ESP32 能收到三類實際元件的資料，不包含正式落下測試、速度計算、校正、資料記錄或 Relay 控制。程式每一個非空程式碼行均附正體中文註解。

測試內容：

1. ADXL375 使用 GPIO21／GPIO22 的 I²C，先掃描匯流排，再以預設位址 `0x53` 初始化，週期性輸出 X／Y／Z 加速度，單位為 `m/s²`。
2. HX711 使用 GPIO32／GPIO33，以 A 通道增益 128 讀取原始 ADC 值；程式不執行重量校正，並對 DATA 未就緒加入 1 秒逾時保護，避免接線錯誤造成永久卡住。
3. OS25B10 光閘一／二分別讀取 GPIO34／GPIO35，輸出實際 HIGH／LOW；依目前電路預期未遮光為 LOW、遮光為 HIGH，但仍須以實物量測確認極性。

本機已用 `C:\Program Files\Arduino CLI\arduino-cli.exe` 搭配 `esp32:esp32:nodemcu-32s` 編譯通過。編譯函式庫為 `Adafruit ADXL375`、`Adafruit HX711` 及其相依函式庫。程式檔案標頭與開機訊息均已註明「尚未實際燒錄驗證」。當次 `board list` 僅辨識到 `COM1 Unknown`，尚未完成 NodeMCU-32S 實機燒錄與感測器讀值驗證。

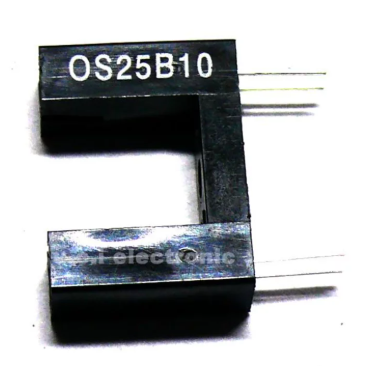
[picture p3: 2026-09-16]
圖片/OS25B10-紅外線對射光電開關.png

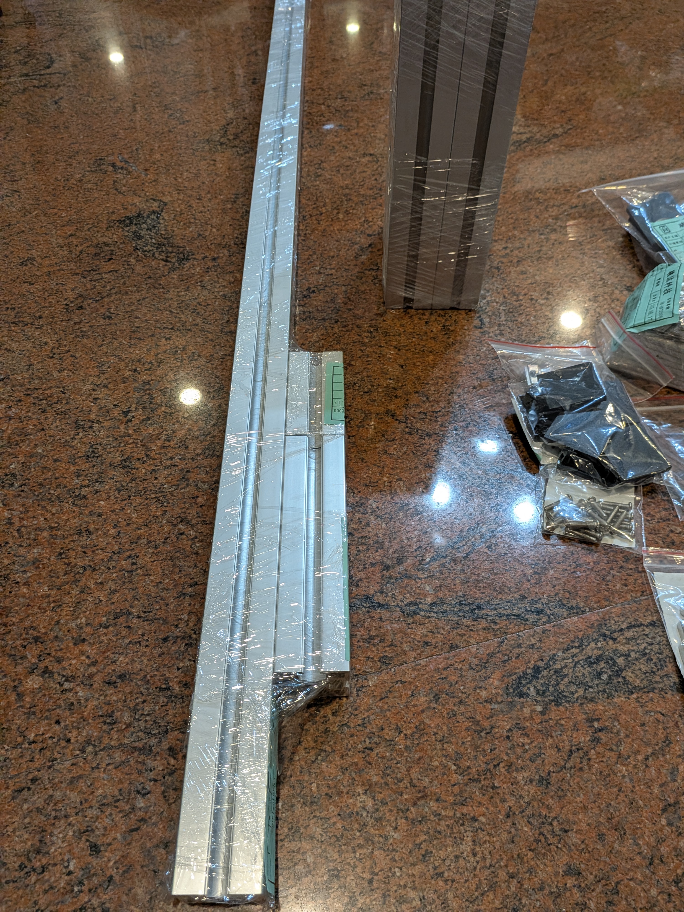
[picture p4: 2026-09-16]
圖片/PXL_20260615_125853231.MP.jpg

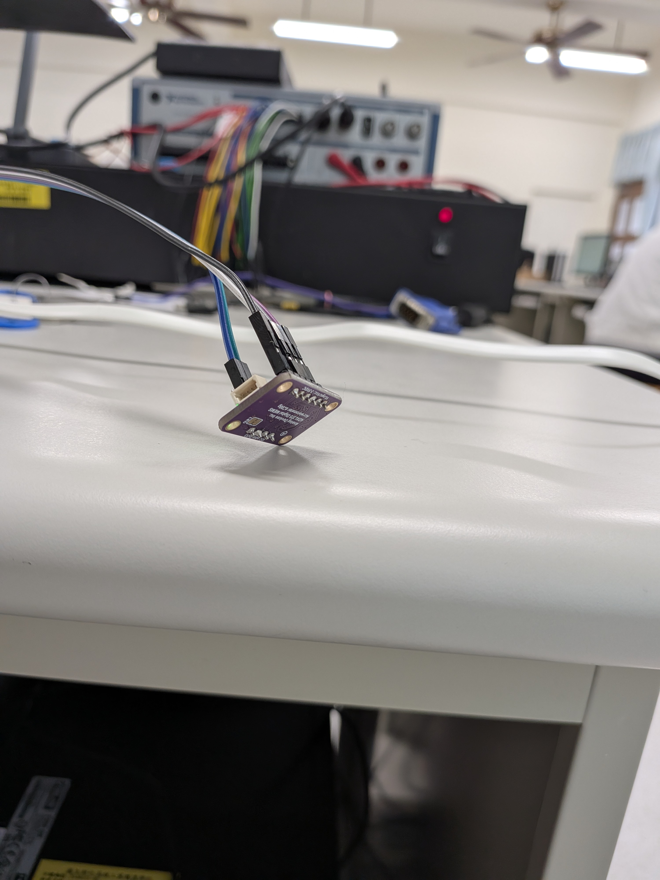
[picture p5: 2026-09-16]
圖片/PXL_20260611_024923133.MP.jpg

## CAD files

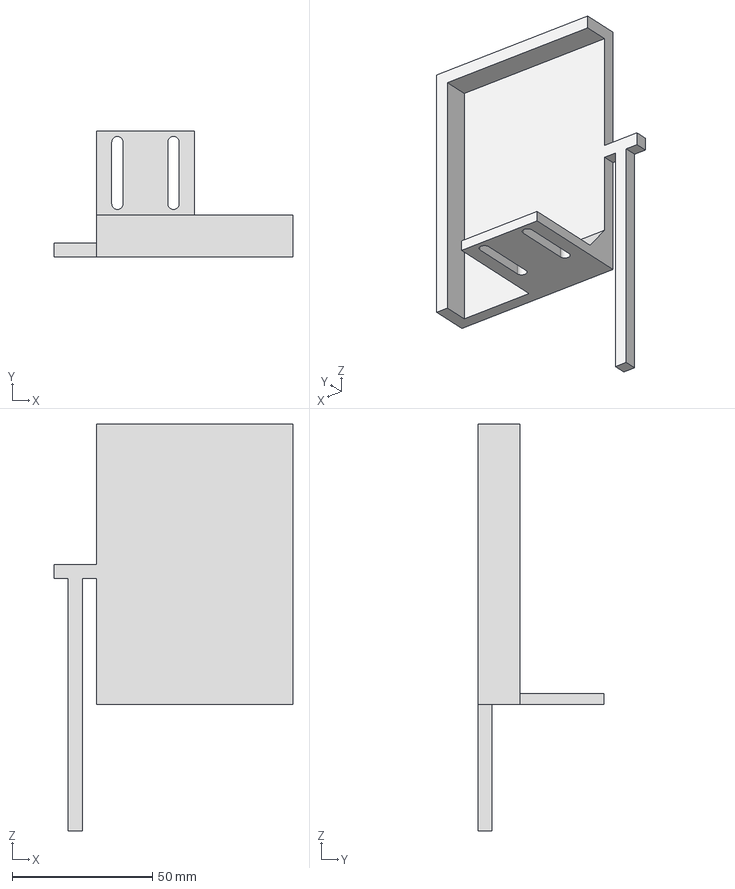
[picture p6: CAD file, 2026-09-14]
零件1.stp
85.0 x 45.0 x 145.0 mm

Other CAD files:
零件1.stl

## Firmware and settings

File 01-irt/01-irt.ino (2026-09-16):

// ============================================================================ // 本檔案為 01-irt.ino 第一版簡易測試程式（簡易測試版）。
// 本程式只驗證 ADXL375、HX711 與兩組 OS25B10 是否能由 ESP32 讀到資料。 // 本行說明測試範圍。
// 本程式不包含正式落下測試、速度計算、校正、資料記錄或 Relay 控制。 // 本行說明目前未包含的功能。
// 本程式目前僅完成編譯檢查，尚未在實體 NodeMCU-32S 上實際燒錄驗證。 // 本行明確標示目前驗證狀態。
// 開啟序列埠監控視窗並設定為 115200 baud，即可查看測試結果。 // 本行說明操作方式。
// ============================================================================ // 本行為檔案標題結束線。

#include <Arduino.h> // 載入 Arduino 基本型別、GPIO、時間與 Serial 功能。
#include <Wire.h> // 載入 I²C 通訊功能，供 ADXL375 使用。
#include <Adafruit_Sensor.h> // 載入 Adafruit Unified Sensor 的事件資料型別。
#include <Adafruit_ADXL375.h> // 載入 Adafruit ADXL375 感測器函式庫。
#include <Adafruit_HX711.h> // 載入 Adafruit HX711 ADC 函式庫。

const uint8_t ADXL375_SDA_PIN = 21; // 設定 ADXL375 SDA 接到 NodeMCU-32S GPIO21。
const uint8_t ADXL375_SCL_PIN = 22; // 設定 ADXL375 SCL 接到 NodeMCU-32S GPIO22。
const uint8_t HX711_DATA_PIN = 32; // 設定 HX711 DATA 接到 NodeMCU-32S GPIO32。
const uint8_t HX711_SCK_PIN = 33; // 設定 HX711 SCK 接到 NodeMCU-32S GPIO33。
const uint8_t OS25B10_GATE1_PIN = 34; // 設定 OS25B10 光閘一 Collector 節點接到 GPIO34。
const uint8_t OS25B10_GATE2_PIN = 35; // 設定 OS25B10 光閘二 Collector 節點接到 GPIO35。
const uint8_t ADXL375_I2C_ADDRESS = 0x53; // 設定 SDO 接地時 ADXL375 的預設 I²C 位址。
const uint32_t SERIAL_BAUD_RATE = 115200; // 設定序列埠傳輸速率為 115200 baud。
const uint32_t REPORT_INTERVAL_MS = 500; // 設定每 500 毫秒輸出一次感測器資料。
const uint32_t HX711_READY_TIMEOUT_MS = 1000; // 設定等待 HX711 DATA 就緒的最長時間。

Adafruit_ADXL375 g_adxl375(12345, &Wire); // 建立使用硬體 I²C 的 ADXL375 物件並指定識別碼。
Adafruit_HX711 g_hx711(HX711_DATA_PIN, HX711_SCK_PIN); // 建立使用 GPIO32 與 GPIO33 的 HX711 物件。
bool g_adxl375_ready = false; // 保存 ADXL375 初始化是否成功的狀態。
bool g_hx711_ready = false; // 保存 HX711 初始化是否完成的狀態。
uint32_t g_last_report_ms = 0; // 保存上一次輸出資料的時間戳。

void printI2CScan(); // 宣告 I²C 掃描函式，先確認 ADXL375 是否出現在匯流排上。
bool readHX711RawWithTimeout(int32_t &raw_value); // 宣告具逾時保護的 HX711 原始值讀取函式。
void printSensorValues(); // 宣告感測器資料輸出函式。

void setup() { // Arduino 開機後只執行一次的初始化函式。
  Serial.begin(SERIAL_BAUD_RATE); // 啟動 USB 序列埠，讓 ESP32 回傳測試結果。
  delay(500); // 等待序列埠與 USB 轉換器穩定。
  Serial.println(); // 在序列埠輸出一個空白行，方便閱讀。
  Serial.println("========================================"); // 輸出測試程式分隔線。
  Serial.println("01-irt.ino：第一版簡易測試程式"); // 明確標示本程式是第一版簡易測試程式。
  Serial.println("注意：本程式尚未實際燒錄驗證，以下輸出格式為預期測試結果。"); // 在開機訊息中明確標示尚未完成實機燒錄驗證。
  Serial.println("測試項目：ADXL375、HX711、OS25B10 光閘一與光閘二"); // 輸出本次測試的元件清單。
  Serial.println("腳位：SDA=21、SCL=22、HX711 DATA=32、SCK=33、光閘=34/35"); // 輸出目前採用的 GPIO 配置。
  Serial.println("========================================"); // 輸出測試程式分隔線。
  Wire.begin(ADXL375_SDA_PIN, ADXL375_SCL_PIN); // 以 GPIO21 與 GPIO22 啟動 ESP32 I²C 匯流排。
  Wire.setClock(100000); // 使用 100 kHz 標準 I²C 速度以利第一版接線測試。
  printI2CScan(); // 掃描 I²C 位址並在序列埠顯示找到的裝置。
  g_adxl375_ready = g_adxl375.begin(ADXL375_I2C_ADDRESS); // 嘗試以 0x53 初始化 ADXL375。
  if (g_adxl375_ready) { // 如果 ADXL375 回應正確，就進入成功處理區塊。
    g_adxl375.setDataRate(ADXL343_DATARATE_100_HZ); // 將 ADXL375 資料率設定為 100 Hz 供測試使用。
    Serial.println("[ADXL375] 初始化成功，可讀取 X/Y/Z 加速度。"); // 回報 ADXL375 已正確回應。
  } else { // 如果 ADXL375 沒有回應，就進入失敗處理區塊。
    Serial.println("[ADXL375] 初始化失敗，請檢查 3V3、GND、SDA、SCL、CS 與 SDO 接線。"); // 回報 ADXL375 接線或位址可能有問題。
  } // 結束 ADXL375 初始化結果判斷。
  g_hx711.begin(); // 初始化 HX711 的 DATA 與 SCK 腳位並喚醒晶片。
  g_hx711_ready = true; // 函式庫已完成初始化，實際資料是否就緒交由迴圈測試。
  Serial.println("[HX711] 腳位初始化完成，將以 A 通道增益 128 讀取原始值。"); // 回報 HX711 已開始等待資料。
  pinMode(OS25B10_GATE1_PIN, INPUT); // 設定光閘一 Collector 節點為輸入，使用外接 10 kΩ 上拉。
  pinMode(OS25B10_GATE2_PIN, INPUT); // 設定光閘二 Collector 節點為輸入，使用外接 10 kΩ 上拉。
  Serial.println("[OS25B10] GPIO34/GPIO35 已設定為輸入，請遮擋兩顆光閘觀察 HIGH/LOW 變化。"); // 回報兩組光閘已開始監看。
  Serial.println("開始週期性輸出測試數值；HX711 若未接妥會在 1 秒後顯示逾時。"); // 說明接線錯誤時不會讓程式永久卡住。
} // 結束 setup 初始化函式。

void loop() { // Arduino 會持續重複執行的主迴圈函式。
  const uint32_t now_ms = millis(); // 取得 ESP32 開機至今的毫秒時間。
  if (now_ms - g_last_report_ms >= REPORT_INTERVAL_MS) { // 到達輸出週期時才讀取並輸出一次資料。
    g_last_report_ms = now_ms; // 更新上一次輸出的時間戳。
    printSensorValues(); // 讀取三類元件並把目前結果輸出到序列埠。
  } // 結束週期輸出判斷。
} // 結束 loop 主迴圈函式。

void printI2CScan() { // 執行一次 I²C 匯流排掃描並輸出結果的函式。
  uint8_t found_count = 0; // 建立找到的 I²C 裝置數量計數器。
  Serial.println("[I2C] 開始掃描 GPIO21(SDA) 與 GPIO22(SCL)..."); // 輸出 I²C 掃描開始訊息。
  for (uint8_t address = 1; address < 127; address++) { // 逐一測試合法的 7-bit I²C 位址。
    Wire.beginTransmission(address); // 對目前位址開始一次 I²C 傳輸。
    const uint8_t error_code = Wire.endTransmission(); // 結束傳輸並取得裝置回應狀態碼。
    if (error_code == 0) { // 回應碼為零代表該位址有裝置回應。
      found_count++; // 將找到的裝置數量加一。
      Serial.print("[I2C] 找到裝置位址 0x"); // 輸出找到的 I²C 位址前綴。
      if (address < 16) { // 位址小於 0x10 時補一個前導零以保持格式一致。
        Serial.print("0"); // 輸出 I²C 位址的前導零。
      } // 結束前導零判斷。
      Serial.println(address, HEX); // 以十六進位輸出目前找到的 I²C 位址。
    } // 結束 I²C 裝置回應判斷。
  } // 結束全部 I²C 位址掃描迴圈。
  if (found_count == 0) { // 如果完全沒有找到 I²C 裝置，就輸出檢查提示。
    Serial.println("[I2C] 沒有找到裝置，ADXL375 可能未供電、未共地或 SDA/SCL 接錯。"); // 回報 I²C 匯流排沒有回應。
  } else if (found_count > 0) { // 如果找到至少一個裝置，就繼續提示預期的 ADXL375 位址。
    Serial.print("[I2C] 預期 ADXL375 位址為 0x53，目前請確認掃描結果包含 0x53。"); // 提示使用者核對 ADXL375 位址。
    Serial.println(); // 結束此行 I²C 提示訊息。
  } // 結束 I²C 掃描結果判斷。
} // 結束 I²C 掃描函式。

bool readHX711RawWithTimeout(int32_t &raw_value) { // 讀取 HX711 A 通道原始值並避免未接線時永久等待。
  const uint32_t start_ms = millis(); // 記錄開始等待 HX711 DATA 就緒的時間。
  while (g_hx711.isBusy()) { // HX711 DATA 為 HIGH 時代表轉換尚未完成。
    if (millis() - start_ms >= HX711_READY_TIMEOUT_MS) { // 等待超過設定時間就判定本次讀取逾時。
      return false; // 回傳失敗，讓主程式繼續測試其他元件。
    } // 結束 HX711 逾時判斷。
    delay(1); // 短暫等待後再次檢查 HX711 DATA 狀態。
  } // 結束 HX711 DATA 就緒等待迴圈。
  raw_value = g_hx711.readChannelRaw(CHAN_A_GAIN_128); // 讀取 A 通道增益 128 的 24-bit 原始值。
  return true; // 回傳成功，表示 ESP32 已收到一筆 HX711 數值。
} // 結束 HX711 具逾時讀取函式。

void printSensorValues() { // 讀取並輸出 ADXL375、HX711 與 OS25B10 的目前數值。
  sensors_event_t adxl375_event; // 建立 Adafruit Unified Sensor 使用的加速度事件資料容器。
  int32_t hx711_raw_value = 0; // 建立存放 HX711 A 通道原始值的變數。
  const int gate1_level = digitalRead(OS25B10_GATE1_PIN); // 讀取光閘一 Collector 節點的數位電位。
  const int gate2_level = digitalRead(OS25B10_GATE2_PIN); // 讀取光閘二 Collector 節點的數位電位。
  Serial.print("[資料] t="); // 輸出資料列的時間欄位前綴。
  Serial.print(millis()); // 輸出 ESP32 開機後經過的毫秒數。
  Serial.print(" ms | "); // 分隔時間欄位與下一個感測器欄位。
  Serial.print("ADXL375: "); // 輸出 ADXL375 欄位名稱。
  if (g_adxl375_ready) { // 只有初始化成功時才向 ADXL375 請求加速度資料。
    g_adxl375.getEvent(&adxl375_event); // 從 ADXL375 讀取最新的 X、Y、Z 加速度事件。
    Serial.print("X="); // 輸出 X 軸欄位名稱。
    Serial.print(adxl375_event.acceleration.x, 3); // 輸出 X 軸加速度，單位為 m/s^2。
    Serial.print(" Y="); // 輸出 Y 軸欄位名稱。
    Serial.print(adxl375_event.acceleration.y, 3); // 輸出 Y 軸加速度，單位為 m/s^2。
    Serial.print(" Z="); // 輸出 Z 軸欄位名稱。
    Serial.print(adxl375_event.acceleration.z, 3); // 輸出 Z 軸加速度，單位為 m/s^2。
    Serial.print(" m/s^2"); // 輸出 ADXL375 加速度的單位。
  } else { // ADXL375 初始化失敗時輸出錯誤狀態而不讀取資料。
    Serial.print("ERROR(未偵測到)"); // 回報 ADXL375 沒有可讀資料。
  } // 結束 ADXL375 資料輸出判斷。
  Serial.print(" | HX711: "); // 輸出 HX711 欄位名稱。
  if (g_hx711_ready && readHX711RawWithTimeout(hx711_raw_value)) { // 嘗試在逾時保護下讀取 HX711 原始值。
    Serial.print("A128_RAW="); // 輸出 HX711 A 通道增益 128 原始值欄位名稱。
    Serial.print(hx711_raw_value); // 輸出 ESP32 從 HX711 收到的原始 ADC 數值。
  } else { // HX711 未就緒或等待逾時時輸出錯誤狀態。
    Serial.print("ERROR(未就緒或 DATA 逾時)"); // 提示檢查 HX711 供電、共地、DATA、SCK 與荷重元接線。
  } // 結束 HX711 資料輸出判斷。
  Serial.print(" | OS25B10-1: "); // 輸出光閘一欄位名稱。
  Serial.print(gate1_level == HIGH ? "HIGH" : "LOW"); // 輸出光閘一的實際數位電位。
  Serial.print(gate1_level == HIGH ? "(預期遮光)" : "(預期未遮光)"); // 依目前電路預期極性說明光閘一狀態。
  Serial.print(" | OS25B10-2: "); // 輸出光閘二欄位名稱。
  Serial.print(gate2_level == HIGH ? "HIGH" : "LOW"); // 輸出光閘二的實際數位電位。
  Serial.println(gate2_level == HIGH ? "(預期遮光)" : "(預期未遮光)"); // 依目前電路預期極性說明光閘二狀態並換行。
} // 結束感測器資料輸出函式。

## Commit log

2026-09-14 Initial project files
    [零件1.stl, 零件1.stp]
2026-09-16 docs: update ESP32 wiring and OS25B10 reference
2026-09-16 feat: add initial sensor wiring test sketch
2026-09-16 docs: mark sensor test as not hardware verified
2026-09-18 docs: update sensor wiring and timing notes
2026-09-18 docs: merge ADXL375 wire colors into pinout tables
2026-09-18 docs: record HX711 breadboard wire colors
2026-09-18 feat: rewrite sensor communication test
2026-10-16 docs: add I2C OLED module image
2026-10-16 feat: add OLED sensor display test and verify ESP32 upload
2026-10-16 fix: test SH1106 driver and document OLED wiring diagnostics
2026-10-16 fix: apply verified SH1106 OLED settings and 3.3V wiring
2026-10-16 docs: record HX711 saturation diagnostics and wiring checks
2026-10-16 docs: confirm HX711 power and black-white wire connections
2026-10-17 docs: plan Tracker Sensor replacement for dual OS25B10 gates
2026-10-17 feat: add compile-verified Tracker Sensor OLED test sketch
2026-10-17 docs: add complete tracker wiring and record verified upload
2026-10-17 docs: verify independent tracker switching after 3V3 rewiring
2026-10-17 fix(docs): correct HX711 VIO digital power wiring
2026-10-17 docs: record pre-VIO voltages and safe power verification
2026-10-17 docs: record HX711 supply path resistance checks
2026-10-17 docs: record isolated HX711 wire tests and board contact checks
2026-10-20 docs: record verified HX711 wiring and SAT recovery
2026-10-21 docs: add complete NMK99 wiring diagram and handoff
2026-10-21 docs: reorganize README around current NMK99 workflow
2026-10-21 Add FIFO diagnostics and record ESP32 3.3.12 build
2026-10-21 docs: record HX711 400g calibration and load cell mounting
2026-10-21 docs: archive HX711 calibration and record fifo-diag1 deployment
2026-10-21 docs: archive fifo-diag1 HX711 calibration and diagnostic photos
2026-10-22 docs: correct HX711 calibration mass to 200g and recalculate measurements
2026-10-22 docs: record calibration progress and next diagnostic steps
2026-10-23 docs: detail impact metrics and calibration acceptance recommendations
2026-10-28 Document HX711 calibration analysis and diagnostic evidence
